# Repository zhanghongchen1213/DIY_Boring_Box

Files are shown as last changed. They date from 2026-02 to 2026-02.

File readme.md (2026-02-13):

# 复刻马里奥经典问号砖，摇一摇出金币，这波回忆杀满分！

> 一款基于 ESP32 主控的"马里奥无聊方块"，专为 DIY 爱好者设计

## 项目简介

本项目是一款复刻经典马里奥问号砖块的互动解压玩具，灵感来源于"Useless Box（无聊盒子）"。当你按下按钮时，盒子会以各种出其不意的方式自己关闭开关——快速、慢速、犹豫、抖动、偷看……每次互动都充满惊喜。

项目基于 ESP32-WROOM 主控，采用 FreeRTOS 实时操作系统，集成 OLED 表情显示、MP3 音效播放和双舵机动作控制，支持 PlatformIO 开发环境。全部硬件设计、3D 模型和固件源码均已开源，适合 DIY 爱好者学习和复刻。

## 开源地址

| 平台 | 链接 |
| --- | --- |
| 个人博客 | [https://zhcmqtt.top](https://zhcmqtt.top) |
| CSDN博客 | [https://blog.csdn.net](https://blog.csdn.net/weixin_46477159?spm=1000.2115.3001.5343) |
| 立创硬件开源 | [https://x.jlc.com](https://oshwhub.com/nhwjxzxz/wu-liao-he-zi-4-12) |
| GitHub项目开源 | [https://github.com](https://github.com/zhanghongchen1213/DIY_Boring_Box) |

**视频演示**

点击观看视频 (https://www.bilibili.com/video/BV12n6sBjEcX/)

> 📺 **视频作者**：B站 @鸿尘客
> 🔗 **视频链接**：[马里奥无聊方块](https://www.bilibili.com/video/BV12n6sBjEcX/)

---

## 应用场景

- ESP32 嵌入式项目学习
- 自主编程开发
- 解压玩具

## 功能特性

| 功能 | 描述 |
| --- | --- |
| 双舵机控制 | 翻盖舵机 (GPIO14) + 推杆舵机 (GPIO12)，支持快开、慢开、抖动、摇摆等动作 |
| OLED 表情  | 0.96 寸 SSD1306 屏幕，开机 GIF 动画，随机切换多种表情 |
| MP3 音效 | 串口控制 MP3 模块，支持多音效集随机播放，可自定义上传音频 |
| 随机行为 | 基于 ESP32 硬件随机数，每次触发动作、表情、音效均随机组合 |
| 惊喜彩蛋 | 随机 10-15 次触发后播放特殊惊喜音效 |
| 电源管理 | 4.2V 锂电池供电，集成充电管理芯片，充电红灯/满电绿灯指示 |
| 便捷烧录 | Micro USB 接口 + 自动下载电路，无需手动配置 IO0/RST |
| 可扩展 | 预留 WiFi/MQTT 网络功能接口，可二次开发实现远程控制 |

## 核心组件

| 组件 | 型号/规格 | 说明 |
| --- | --- | --- |
| 主控芯片 | ESP32-WROOM-32 | 双核 240MHz，支持 WiFi/蓝牙 |
| OLED 显示屏 | 0.96 寸 SSD1306 | I2C 接口，128x64 分辨率 |
| MP3 模块 | 串口 MP3 播放模块 | 支持 TF 卡，串口指令控制 |
| 舵机 | SG90 x 2 | 翻盖舵机 + 推杆舵机 |
| 电池 | 4.2V 聚合物锂电池 | 配合板载充电管理电路 |
| 触发开关 | 纽子开关 | 用户交互输入 |
| USB 接口 | Micro USB | 充电 + 固件烧录 |

## 软件架构

- **开发框架**：Arduino + PlatformIO
- **操作系统**：FreeRTOS 多任务调度
- **核心库依赖**：
  - `ESP32Servo` - 舵机 PWM 控制
  - `U8g2` - OLED 图形驱动
  - `ArduinoJson` - JSON 数据解析
  - `PubSubClient` - MQTT 通信（可选）

## 预览图

### PCBA 预览

| PCBA 正面 | PCBA 反面 |
| :---: | :---: |
| PCBA正面 (https://imgloc.com/image/yWQs7x) | PCBA反面 (https://imgloc.com/image/yWQ9AM) |

### 接线图

配件接线图 (https://imgloc.com/image/yWQDJr)

_图：配件接线示意图_

### 3D 渲染图

| 渲染图 1 | 渲染图 2 | 渲染图 3 |
| :---: | :---: | :---: |
| 3D渲染1 (https://imgloc.com/image/yWQHcq) | 3D渲染2 (https://imgloc.com/image/yWQJ8C) | 3D渲染3 (https://imgloc.com/image/yWQYl4) |

### 实物图

| 实物展示 1 | 实物展示 2 |
| :---: | :---: |
| 实物图1 (https://imgloc.com/image/yWQEAN) | 实物图2 (https://imgloc.com/image/yWQdJH) |

## 项目目录

```
03_boring_box/
├── 01_UI设计/                # UI 素材资源
│   ├── GIF/                  # GIF 动画素材
│   ├── 舔狗表情/             # OLED 显示表情图片
│   ├── 音效集/               # MP3 音频文件
│   └── 马里奥无聊方块-封面.png
├── 02_三维模型/              # 3D 打印模型文件
│   ├── 3D打印/               # 可直接打印的 STL 文件
│   ├── 外购/                 # 外购配件模型参考
│   ├── 马里奥盒子主体.SLDPRT # 主体外壳
│   ├── 马里奥盒子底座.SLDPRT # 底座
│   ├── 马里奥盖子.SLDPRT     # 顶部翻盖
│   ├── 马里奥问号.SLDPRT     # 问号装饰
│   ├── 马里奥键帽.SLDPRT     # 按键帽
│   ├── 开盖杆.SLDPRT         # 翻盖连杆
│   ├── 无聊杆.SLDPRT         # 无聊舵机连杆
│   └── ...                   # 其他零件
├── 03_采购清单/              # 物料清单
│   ├── BOM.xls               # 元器件清单
│   └── 采购清单.xlsx         # 采购明细表
├── 04_firmware/              # 固件源码
│   ├── Boring_box/           # Arduino 工程源码
│   └── 模块数据手册/         # 芯片及模块数据手册
├── 05_固件烧录/              # 烧录工具及说明
│   ├── firmware_bin/         # 编译好的固件文件
│   ├── flash_download_tool_3.9.6_0.zip  # ESP32 烧录工具
│   └── 烧录必看.docx         # 烧录操作指南
└── readme.md                 # 项目说明文档
```

## 使用说明

1. **硬件准备**：本模块包含硬件与软件设计，焊接完成后需要烧录程序才能使用
2. **供电方式**：模块使用 4.2V 聚合物电池供电，并通过 5V 的 Micro USB 接口充电
3. **3D 打印**：提供 3D 模型文件，需要使用 3D 打印技术打印零件并组装
4. **开源资料**：PCB、3D 模型、源码全部开源，配件信息请查阅附件

## 固件烧录

### 烧录步骤

烧录工具界面 (https://imgloc.com/image/yWQKLX)

_图：Flash 烧录工具参数配置_

1. 下载并安装 CH340 驱动，配置 COM 口
2. 确保参数设置正确（可检索 ESP32 芯片 Flash 烧录查看具体步骤）
3. **重要**：下载前需要同时连接电池和 USB，MCU 才会正常供电
4. 板载自动下载电路，无需配置 IO0 和 RET 即可实现自动烧录
5. 若出现烧录失败，可尝试降低波特率

> ⚠️ **注意**：单 Micro USB 接口供电时不会经过稳压芯片，因此下载固件前需要同时连接电池和 USB

## 音频烧录

### 操作方法

1. 可直连 MP3 模块，通过复制粘贴直接进行音频烧录
2. 个人常用音频上传至 **音效集 03**
3. 惊喜音效上传至 **音效集 02** 并改名替换源文件（惊喜音效会随机在 10-15 次内触发）

### 自定义随机播放数量

若需实现随机播报，需修改源代码中 `random_count` 总数量并重新烧录代码。

代码修改示例 (https://imgloc.com/image/yWQNTg)

_图：random_count 参数修改示例_

> 程序源码提供 MP3 驱动代码，可结合数据手册自行修改

## 注意事项

| 项目 | 说明 |
| --- | --- |
| 接口核对 | 由于板载接口较多，请务必仔细核对各配件对应的接口  |
| OLED 驱动 | 采用 SSD1306 芯片，使用其他芯片时需要自行移植代码 |
| 3D 打印精度 | 部分设计采用内置螺纹，需要确保打印机精度满足要求  |
| OLED 固定 | 内部使用热熔胶固定，如需开孔固定可自行修改模型 |

### 装配顺序

为保持外部造型美观，模块主要采用内部固定方式。装配时请按以下顺序操作：

```
固定电池 → 固定纽子开关 → 固定无聊舵机 → 固定翻盖舵机 → PCB接线 → 底座固定MP3 → 底座固定PCB → 固定底座 → 连接翻盖
```

## 开源协议

本项目采用 MIT 协议开源，欢迎 Star 和 Fork！

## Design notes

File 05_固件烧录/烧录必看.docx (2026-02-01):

### 1.Flash烧录

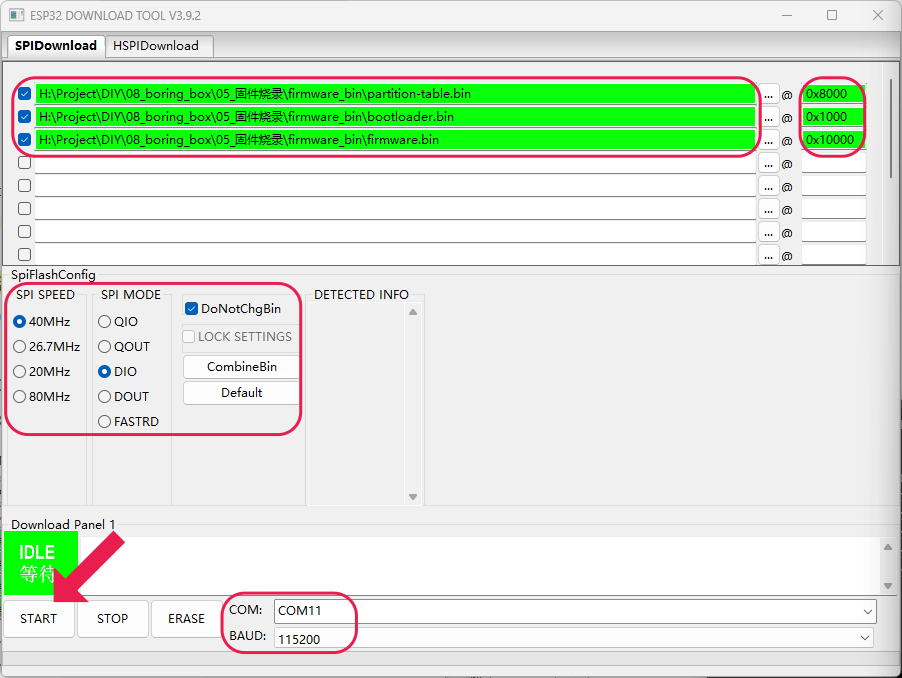
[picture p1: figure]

注意事项：

（1） 需自行下载CH340驱动，配置COM口
（2） 注意参数设置正确，可检索ESP32芯片Flash烧录查看具体烧录步骤
（3） 单Micro_usb接口不会经稳压向MCU供电，下载前需要把电池和USB都接上，MCU才会正常供电
（4） 板载自动下载电路，无需配置IO0和RET即可实现自动烧录
（5） 若出现烧录失败时，可以降低波特率测试

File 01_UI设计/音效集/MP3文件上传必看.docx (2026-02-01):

### 1.音效烧录

注意事项：

（1） 可直连MP3模块，通过复制粘贴直接音频烧录。
（2） 可将个人常用音频上传至音效集03，惊喜音效上传至个人音效集02并改名替换源文件。惊喜音效会随机在10-15次内触发。
（3） 若需实现随机播报，需修改源代码中random_count总数量并重新烧录代码。

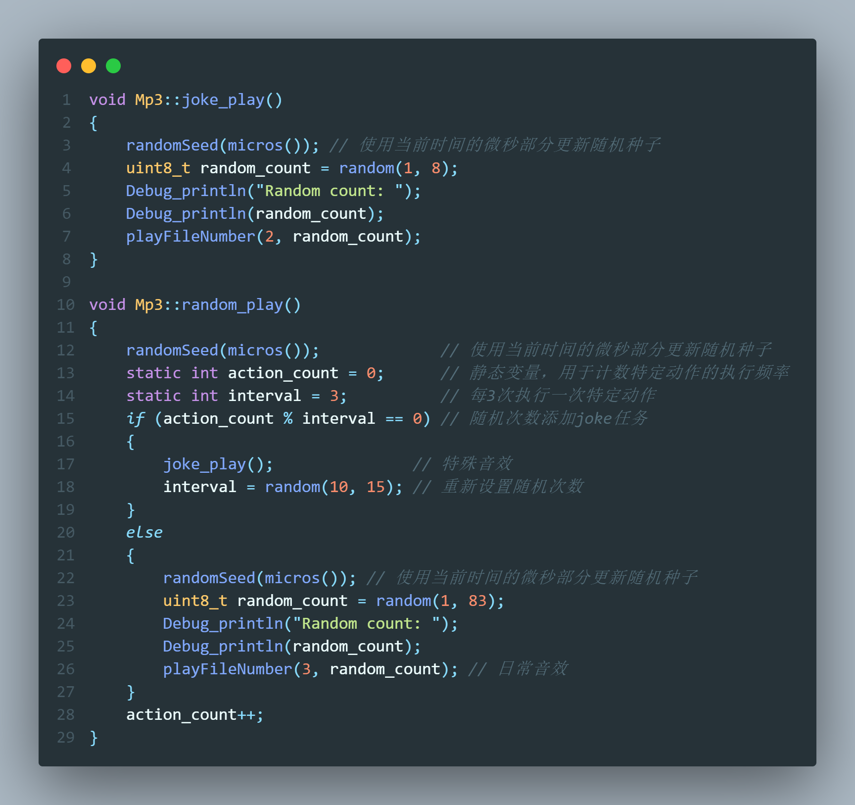
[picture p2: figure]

如音效集02最后总文件为050xxx，joke_play()中random_count=random(1,8)应修改为random(1,51)

如音效集03最后总文件为100xxx，random_play()中random_count=random(1,83)应修改为random(1,101)

（4） 程序源码提供MP3驱动代码，可结合数据手册自行修改代码；

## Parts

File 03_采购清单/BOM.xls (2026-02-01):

Comment型号 | Designator位号 | Footprint封装 | LCSC Part#嘉立创元件编号(可不填)
10uF | C1,C2,C3,C5 | C0805 | C15850
100nF | C4,C6,C7,C10 | C0603 | C30926
22uF | C8 | C0805 | C45783
1uF | C9 | C0603 | C59302
HC-1.25-3PWT | CN2,CN3 | CONN-SMD_HC-1.25-3PWT | C2845380
MBR0530 | D1 | SOD-123_L2.7-W1.6-LS3.7-RD-1 | C475718
NCD0603G1 | GRE | 0603 | C84267
WAFER-PH2.0-4PWB | OLED,U5 | CONN-SMD_4P-P2.00_XUNPU_WAFER-PH2.0-4PWB | C3029442
1x2P 间距:1.25mm 卧贴 | KEY,POWER | SMD,P=1.25mm,卧贴 | C2905009
0Ω | R1 | R0603 | C15402
2kΩ | R2,R3,R4 | R0603 | C22975
1kΩ | R5 | R0603 | C22548
4.7kΩ | R6 | R0603 | C99782
10kΩ | R7,R8 | R0603 | C99198
NCD0603R1 | RED,RED1 | 0603 | C84263
TS3625A | RST | KEY-SMD_L6.0-W3.5-LS8.4 | C398053
TK-6580A-1 | SW1 | SW-TH_TK-6580A-1 | C528770
ESP32-WROOM-32E-N4(4MB) | U1 | WIFI-SMD_ESP32-WROOM-32E-A | C7463334
CH340X | U2 | MSOP-10_L3.0-W3.0-P0.50-LS5.0-BL | C3035748
AMS1117-3.3 | U3 | SOT-223-3_L6.4-W3.5-P2.30-LS7.0-BR | C2992570
TP4056 | U4 | ESOP-8_L4.9-W3.9-P1.27-LS6.0-BL-EP | C725790
U-F-M5DD-Y-1 | USB1 | MICRO-USB-SMD_U-F-M5DD-Y-1 | C91467

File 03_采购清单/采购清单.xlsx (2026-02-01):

单品 | 规格 | 用途 | 链接 | 备注
五金件
螺母 | M2 4个 | 固定舵机 | https://detail.tmall.com/item.htm?_u=22gdhddl8425&id=608573923288&spm=a1z09.2.0.0.61212e8drsddDP
销轴 | φ2 2个 | 翻盖转轴
平头螺钉 | M2* 7 4个 | 固定舵机
平头螺钉 | M3*10 2个 | 翻盖转轴杆连接
沉头螺钉 | M3*14 4个 | 固定底座
平头螺钉 | M3*12 7个 | 固定电池/PCB
平头螺钉 | M4*8 2个 | 固定MP3模块
迷你棘轮扳手 | 批头款+10批头+加磁器+袋 |  | https://mobile.yangkeduo.com/goods2.html?goods_id=298132817097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 | 拼夕夕
胶枪 | 黑色专业40w+15胶棒 |  | https://mobile.yangkeduo.com/goods2.html?goods_id=514015794872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
配件
锂电池 | 军绿色103450 |  | https://detail.tmall.com/item.htm?_u=22gdhddlf523&id=747959753061&skuId=5155750512209
纽子开关 | MTS-102（3脚2档） |  | https://item.taobao.com/item.htm?_u=22gdhddl8c4a&id=543610229454&skuId=5062598072103
OLED屏幕 | 【未焊排针】0.96寸OLED 4针（蓝色显示） |  | https://detail.tmall.com/item.htm?_u=22gdhddlbeeb&id=626422606820&skuId=4441508017606 | SSD1306芯片
MP3模块 | 模块+PH2.0端子线/公对公 |  | https://item.taobao.com/item.htm?_u=22gdhddlcc6b&id=656383490674&skuId=4906066498988
MCU | ESP32-WROOM-32EFlash：4MB |  | https://item.taobao.com/item.htm?_u=22gdhddlf01e&id=599333795323&skuId=4544240284081
舵机*2 | MG90S舵机金属齿旋转180 |  | https://item.taobao.com/item.htm?_u=m2gdhddla686&id=745032337773&skuId=5136658920260
接线端子
OLED屏幕线 | PH2.0 4P转杜邦2.54-1P 20cm(5条) | 板载PH2.0转OLED杜邦 | https://detail.tmall.com/item.htm?_u=22gdhddlbf20&id=723974055577&skuId=5026836212462
舵机线*2 | 3p-1.25mm公转舵机母 | 板载1.25转舵机接口 | https://item.taobao.com/item.htm?_u=22gdhddl5f12&id=601446735804&skuId=4202288864712
纽子开关线 | 1.25mm 公头线 20cm 2P (10条） | 板载1.25转纽子焊接线 | https://detail.tmall.com/item.htm?_u=32gdhddld7e1&id=621628790021&skuId=5050342859876

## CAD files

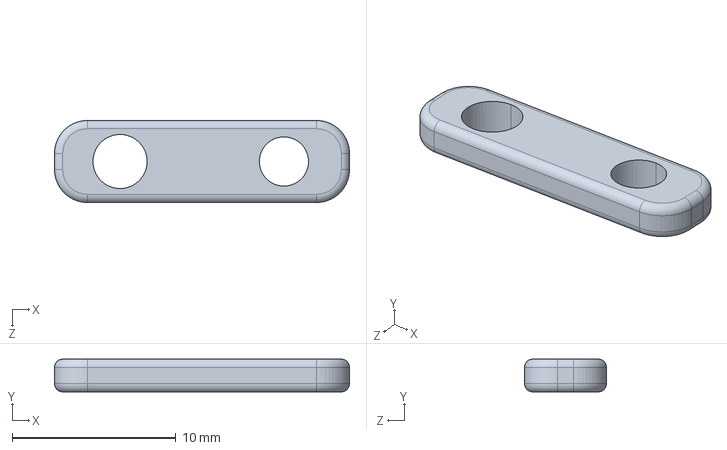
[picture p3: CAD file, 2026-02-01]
02_三维模型/3D打印/开盖杆.STEP
18.0 x 2.00 x 5.00 mm

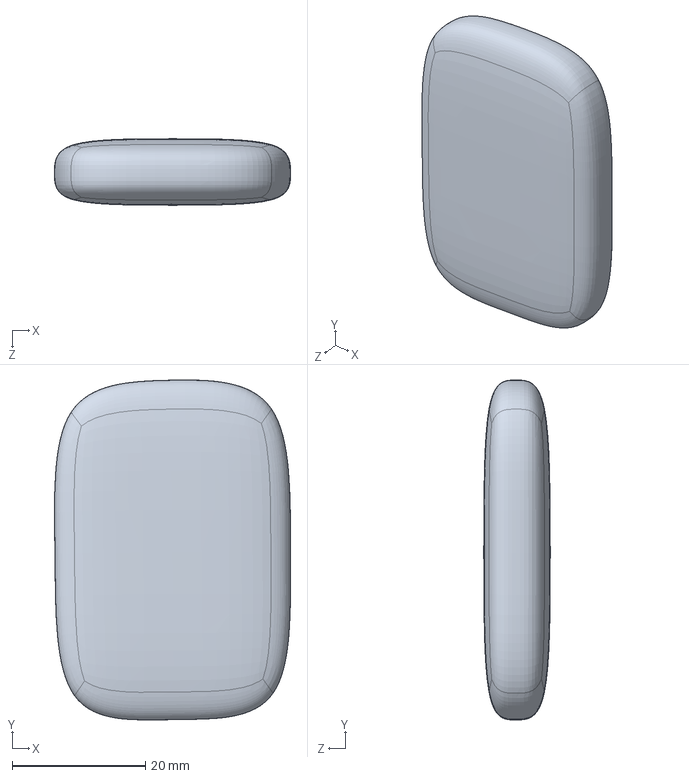
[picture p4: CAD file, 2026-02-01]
02_三维模型/外购/电池.SLDPRT
35.5 x 51.1 x 10.0 mm

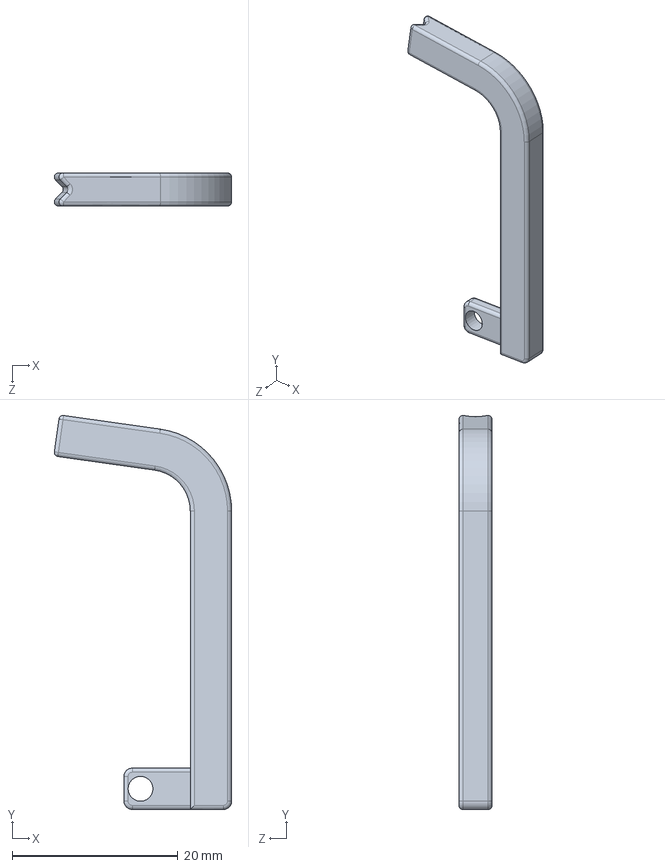
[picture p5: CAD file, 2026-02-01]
02_三维模型/无聊杆.SLDPRT
21.4 x 47.5 x 4.00 mm

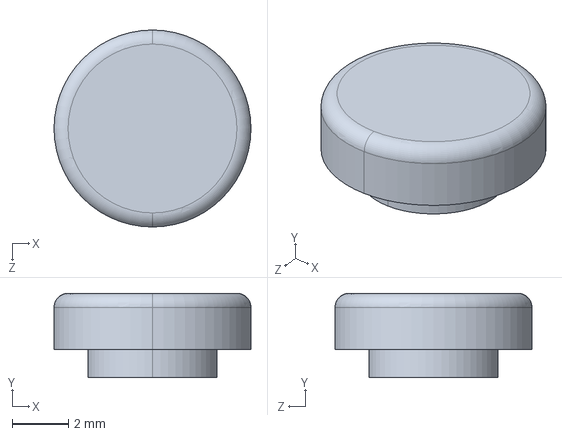
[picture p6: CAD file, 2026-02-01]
02_三维模型/3D打印/马里奥键帽_16.STEP
7.00 x 3.00 x 7.00 mm

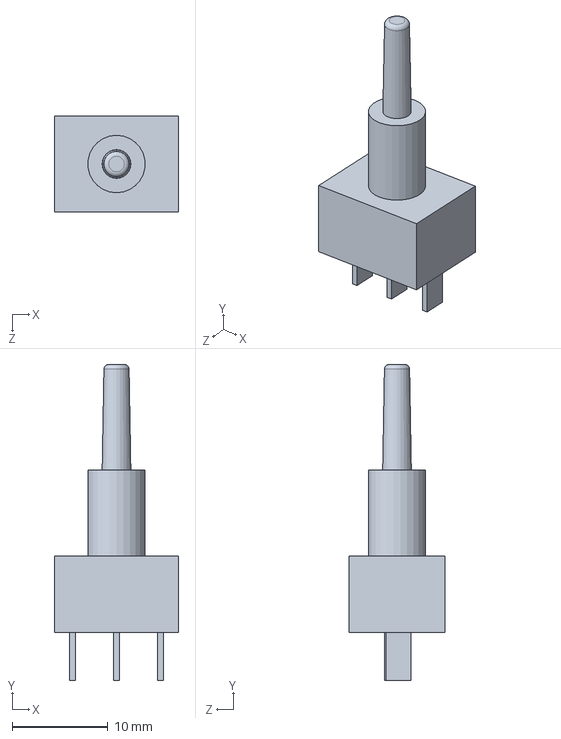
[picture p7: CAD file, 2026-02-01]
02_三维模型/外购/开关.SLDPRT
13.0 x 33.0 x 10.0 mm

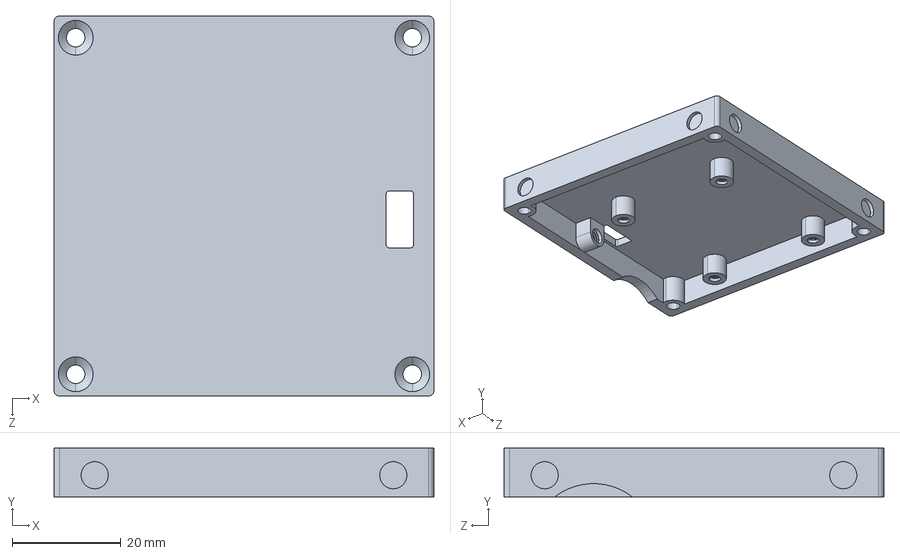
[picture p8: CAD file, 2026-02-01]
02_三维模型/3D打印/马里奥盒子底座.STEP
70.0 x 9.00 x 70.0 mm

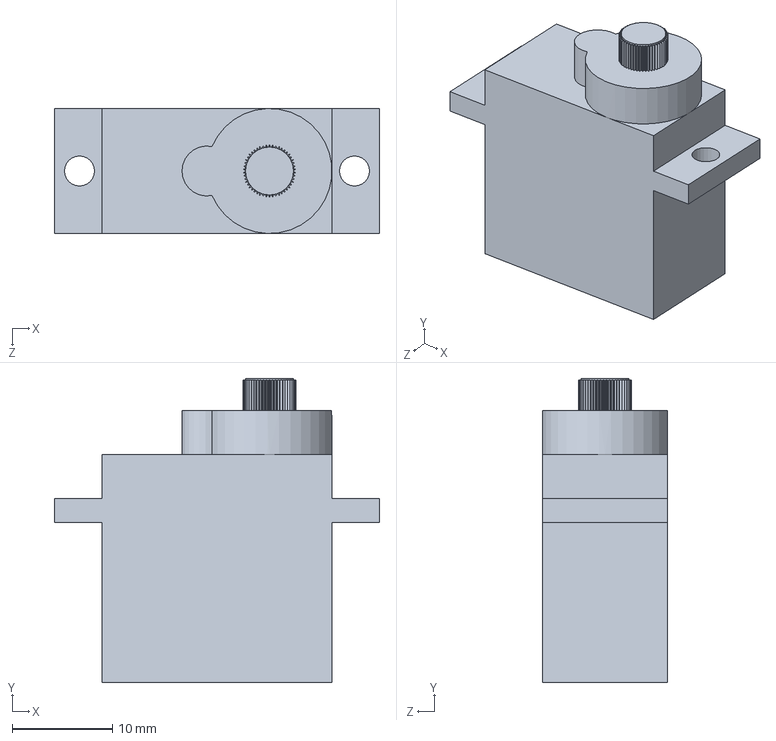
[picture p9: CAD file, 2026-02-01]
02_三维模型/外购/MG90S舵机.SLDPRT
32.5 x 30.4 x 12.5 mm

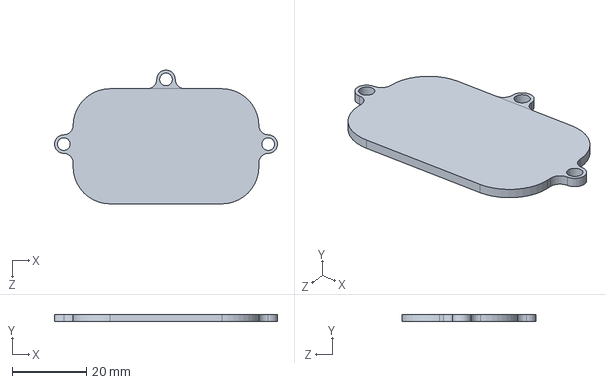
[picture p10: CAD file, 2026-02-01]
02_三维模型/电池盖板.SLDPRT
60.0 x 2.00 x 36.0 mm

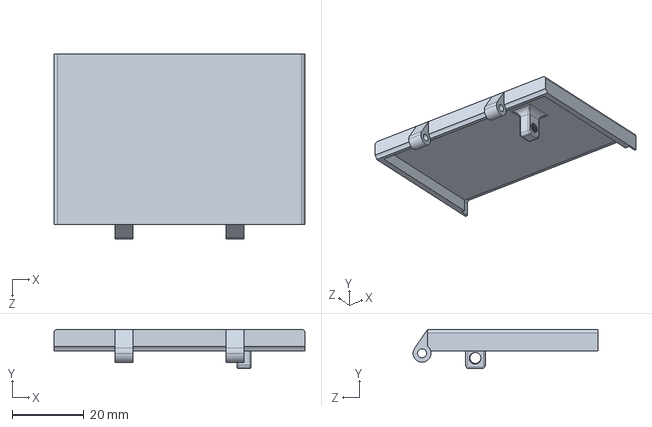
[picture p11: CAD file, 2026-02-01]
02_三维模型/3D打印/马里奥盖子.STEP
70.0 x 11.0 x 51.6 mm

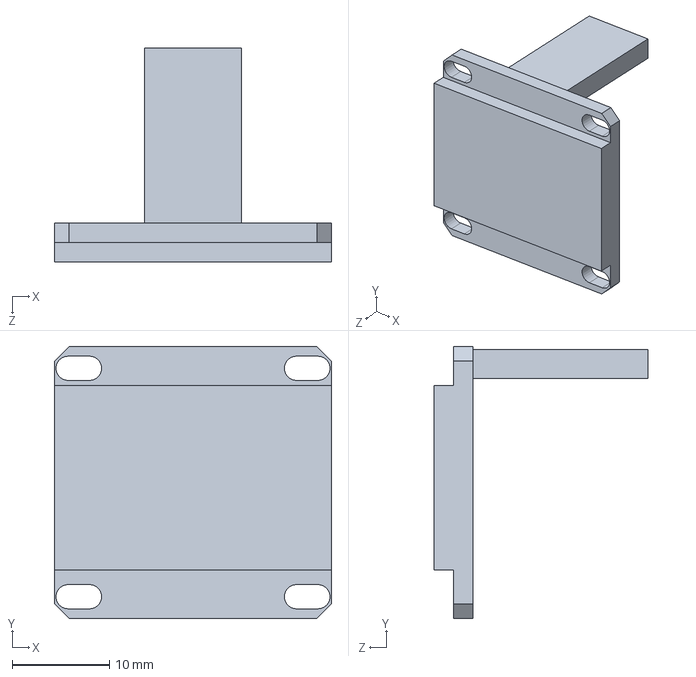
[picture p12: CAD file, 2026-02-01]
02_三维模型/外购/OLED模块.SLDPRT
28.5 x 28.0 x 22.0 mm

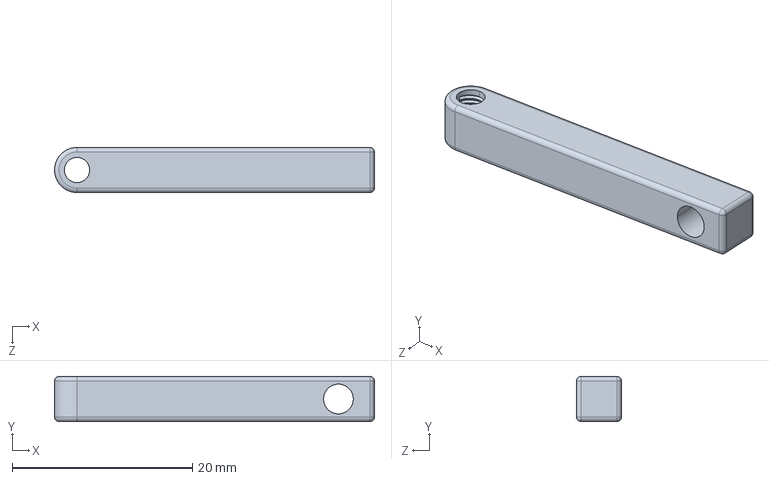
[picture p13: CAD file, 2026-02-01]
02_三维模型/3D打印/开盖杆B.STEP
35.5 x 5.00 x 5.00 mm

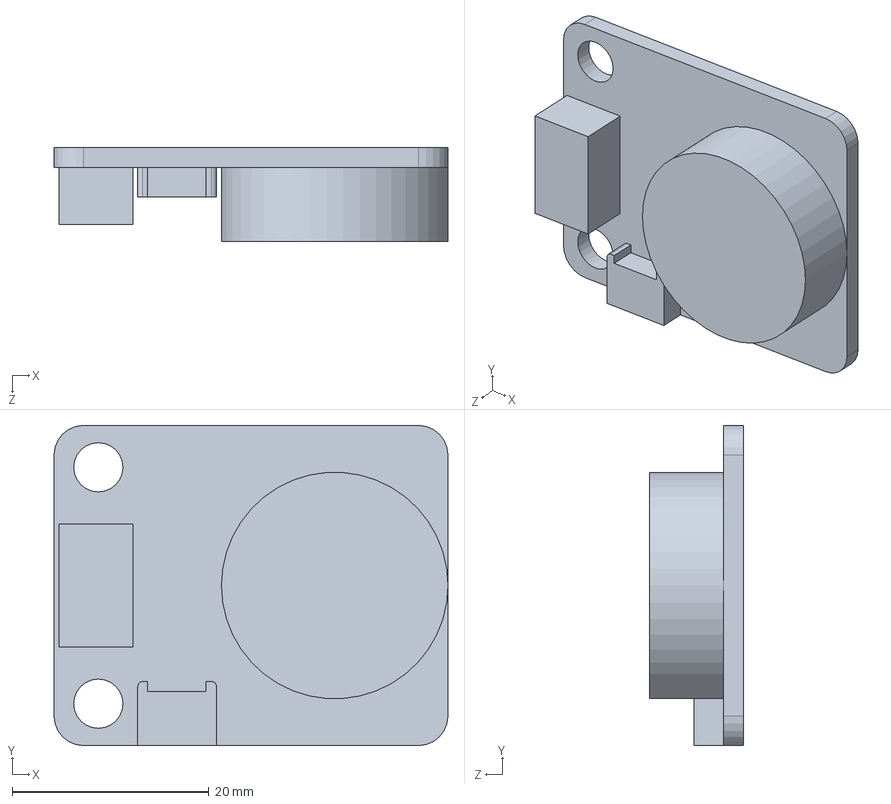
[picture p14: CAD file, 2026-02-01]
02_三维模型/外购/MP3模块.SLDPRT
40.0 x 32.5 x 9.50 mm

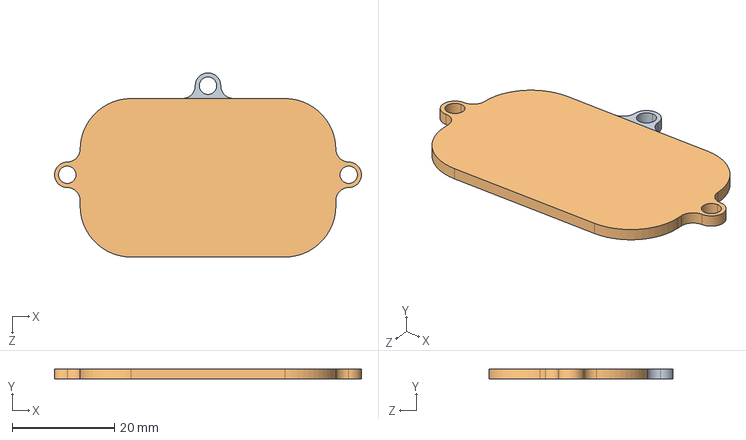
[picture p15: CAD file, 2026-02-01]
02_三维模型/3D打印/电池盖板.STEP
60.0 x 2.00 x 36.0 mm

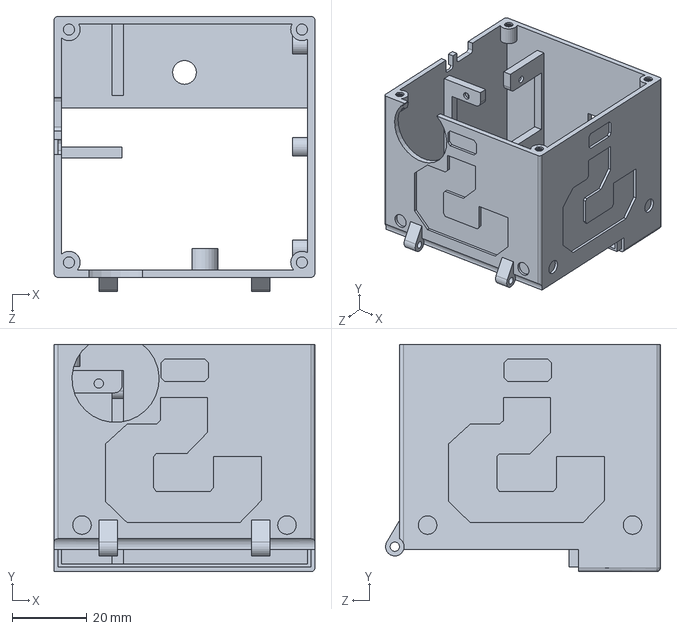
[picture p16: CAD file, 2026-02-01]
02_三维模型/马里奥盒子主体.SLDPRT
70.0 x 61.0 x 73.8 mm

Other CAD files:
02_三维模型/开盖杆.SLDPRT
02_三维模型/马里奥盖子.SLDPRT
02_三维模型/马里奥盒子底座.SLDPRT
02_三维模型/3D打印/马里奥盒子主体.STEP
02_三维模型/3D打印/拓竹参数参考.3mf
02_三维模型/3D打印/无聊杆.STEP
02_三维模型/3D打印/马里奥小问号.STEP
02_三维模型/3D打印/马里奥问号_3.step
02_三维模型/开盖杆B.SLDPRT
02_三维模型/马里奥小问号.SLDPRT
02_三维模型/马里奥键帽.SLDPRT
02_三维模型/马里奥问号.SLDPRT

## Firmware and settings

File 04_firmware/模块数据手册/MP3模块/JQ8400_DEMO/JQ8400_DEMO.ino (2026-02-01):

#include "EM_JQ8400.h"

EM_JQ8400 JQ8400_Device(8, A1); //实例化一个JQ8X00对象,忙检测IO引脚为2号，关闭忙检测功能。注意：忙检测功能为关闭状态将不会配置忙检测引脚
void setup()
{
  uint8_t MakeUp_buffer[2] = {2, 1};          //组合播放内容
  Serial.begin(9600);                         //必须初始化串口，波特率固定为9600不可更改
  delay(500);                                 //上电延时一段时间等待模块稳定之后字发送控制指令
  JQ8400_Device.Command_Data(SetVolume, 30);  //设定音量为30
  delay(10);                                  //连续通信加入一定的延时等待模块处理完上一条指令
//  JQ8X00_Device.MakeUpPlay(MakeUp_buffer, 2); //组合播放指令，依次播放ZH文件夹下的02 01 音频
}

void loop()
{
  JQ8400_Device.Command(Play);
  delay(5000);
  // put your main code here, to run repeatedly:
}

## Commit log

2026-02-01 feat: 添加项目资源文件，包括UI设计、3D模型和固件等
    - 添加UI设计相关的GIF动画、音效文件和启动logo素材
    - 添加3D模型文件（SolidWorks格式）用于外壳和内部结构设计
    - 添加BOM清单和采购清单文档
    - 添加固件二进制文件（bootloader、firmware、partition-table）
    - 添加固件烧录工具和相关文档
    [BOM.xls, MG90S舵机.SLDPRT, MP3模块.SLDPRT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]
2026-02-01 docs: 更新GitHub项目开源链接为正确的仓库地址
